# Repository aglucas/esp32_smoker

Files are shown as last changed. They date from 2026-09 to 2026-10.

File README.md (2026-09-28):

# esp32_smoker

ESP32 firmware project for a smoker controller, built on [ESP-IDF v5.5.3](https://github.com/espressif/esp-idf/releases/tag/v5.5.3). Targets the [Seeed Studio XIAO ESP32C3](https://wiki.seeedstudio.com/XIAO_ESP32C3_Getting_Started/).

## Features

- 3 NTC thermistor probes (probe 0 = pit, 1..2 = meat), read in °F. Beta model by default, or per-probe Steinhart-Hart coefficients once calibrated. Unplugged/shorted probes show as `--`.
- Phone-friendly web dashboard at `http://smoker.local` (mDNS) or the device IP: live temps, pit low/high alarm, pit target and per-probe meat targets, and a graph (pit target drawn as a green line, low/high as red lines) of the last 1/2/3/6 hours with touch/hover readout. Fully self-contained (no CDN), so it also works on the offline setup AP.
- Alerts: pit too low (only after it stays low for the "Low alarm delay", 60 s by default and set on the pit card, so opening the lid doesn't trigger it, and only armed once the pit first reaches temp), pit too high, pit probe lost, meat "almost done", meat done. Delivered by [ntfy.sh](https://ntfy.sh) push notifications (set up from the dashboard). Settings are saved in NVS.
- Wi-Fi: tries `DEFAULT_STA_SSID`, then credentials saved in NVS; if neither connects it falls back to a SoftAP (`ESP32-Smoker-XXXX`, password `smoker1234` by default) and the dashboard shows a network picker. Alerts need internet, so none are sent in AP mode (they queue until it reconnects). While in AP mode it retries your Wi-Fi every 60 s (`WIFI_RECONNECT_SEC`) in the background, keeping the AP up meanwhile, and switches back automatically once it connects.
- Graph history: one sample every 30 s for 12 h, kept in RAM. After a power cut, once the clock syncs over the internet (a few seconds after Wi-Fi connects), the graph reloads the last 12 h from the flash log at 1-minute resolution. The outage shows as a break in the lines. On the offline setup AP the clock never syncs, so the graph starts empty (the flash log still has everything).
- Flash log: one CSV row per minute (`uptime_s,unix_time,local_time,<probe>_f...`) saved to a LittleFS partition in the ESP32's internal flash, so no SD card is needed. Download it from the dashboard's **Data log** panel. **Start new recording** (next to it) deletes the log, clears the graph, and re-arms alerts and the meat target-hit checks; settings are kept. `unix_time` and `local_time` (Mountain Time, set by `LOG_TIMEZONE`) are blank until SNTP syncs. When the active file passes 1 MB it is rotated, and the oldest data is dropped, so the log keeps roughly the last 2-4 weeks of cooking.
- Cook steps: named, timed plans (for example "3-2-1 ribs") edited in the **Cook steps** panel. Each step has a name, minutes, an action and a target temp. Plans are saved on the LittleFS partition (`plans.json`); up to 10 plans with up to 12 steps each. **Start** sends step 1's alert right away, then each next step's alert when the previous step's time is up (for example "Step 2/4: The wrap (120 min) - wrapped in foil ribs. Target 120F"), and a final "all steps done" alert. The target temp is only shown in the alert. The running plan is saved too, so after a power cut it resumes once the clock syncs, and a step that began during the outage is sent late with a note.
- Fan control: a 12 V PC fan on GPIO6 (D4) through a 2N2222, driven by slow (50 Hz) PWM, which lets a 2/3-wire PC fan run steadily at lower speeds than fast PWM. **Auto** runs a PID that holds the pit target (starting with Kp = 4 %/°F, Ki = Kd = 0); **Manual** holds a fixed %; **Off**. In Auto the fan is off when no pit target is set or the pit probe has no reading. If the pit reaches the high alarm, the fan turns off and stays off until the pit has cooled back down to the target. The PID output (0-100 %) drives the fan directly; with slow PWM the fan runs steadily down to about 5 %, and any non-zero output below that is raised to 5 % (`FAN_MIN_PCT`). A 1 s full-speed kick runs when the fan starts from stopped. **Fan alert** (Auto mode): if the fan stays at or above a set % for a set time (90 % for 15 min by default, both set in the Fan panel, 0 = off), one alert is sent to say the fire may be low on fuel or the vents may be wrong; it re-arms once the fan drops below that %. The fan % is plotted on its own graph (0-100 %, half the height) under the temperature graph, sharing its time axis, and logged in the CSV (`fan_pct`).
- JSON API: `GET /api/now`, `GET /api/history`, `POST /api/settings` (form-encoded `alertsOn`, `pitLow`, `pitHigh`, `pitTarget`, `pitLowDelay`, `t1`, `t2`), `POST /api/test`, `GET /api/log.csv`, `POST /api/reset`, `POST /api/hit/clear` (`{"probe":1}`, clears a meat target-hit check), `POST /api/fan` (`{"mode":"auto","manual":50,"kp":4,"ki":0,"kd":0,"alertPct":90,"alertMin":15}`), `POST /api/ntfy` (`{"enabled":true,"server":"https://ntfy.sh","topic":"..."}`), `GET/POST /api/plans`, `POST /api/plan/start` (`{"name":"..."}`), `POST /api/plan/stop`, `GET /api/scan`, `POST /api/wifi` (`{"ssid":"...","password":"..."}`).

## Wiring

Each probe is a voltage divider: `3V3 → rRef → pin → thermistor → GND`. Probes must be on ADC1. The XIAO exposes only three ADC1 pins (A0-A2); A3 is on ADC2, which is unreliable on the C3 and blocked by ESP-IDF.

| Signal | XIAO pin | GPIO | Notes |
|---|---|---|---|
| Pit probe | A0 | GPIO2 | ADC1_CH2, rRef 100k (see strapping note) |
| Meat 1 | A1 | GPIO3 | ADC1_CH3, rRef 100k |
| Meat 2 | A2 | GPIO4 | ADC1_CH4, rRef 100k |
| Fan | D4 | GPIO6 | PWM to the 2N2222 base (see fan note) |

- **Probes and resistor values:** all three probes are Maverick ET-72/73 style (about 200 kΩ at room temperature) on 100k divider resistors, using HeaterMeter's Steinhart-Hart coefficients for that probe (`MAVERICK_SH` in [main/config.h](main/config.h)). They were verified against a 180 °F oven and boiling water (about 202 °F at 5,400 ft). The C3's ADC is only accurate up to about 2.5 V (the classic ESP32 reaches about 3.1 V), so below about 49 °F a probe can't be told apart from an unplugged one, and the dashboard shows "below 49° or unplugged".
- **Strapping pin:** GPIO2 (A0) is sampled at reset to choose the boot mode. The pit probe on A0 holds it at 3.3 V when unplugged and about 2.2 V at room temperature. If the board ever fails to boot with the pit probe plugged in, unplug it during power-up.
- **Fan:** GPIO6 → ~220 Ω → 2N2222 base; emitter to GND; collector to the fan's black (−) wire; fan red (+) to 12 V. The 12 V supply's ground must be connected to the XIAO's GND. Add a diode (1N4148 or 1N5819) across the fan, cathode to +12 V, to absorb switching spikes, and a 10 kΩ resistor from base to GND so the fan stays off while the board boots. Around 220 Ω gives the base roughly 10 mA, enough to fully switch a typical 0.1-0.3 A PC fan (1 kΩ may leave the transistor only part-on and hot).
- **Antenna:** the XIAO ESP32C3 needs its external antenna attached for usable Wi-Fi range.

Probe names, pins, resistor values and thermistor constants are in `PROBE_TABLE` in [main/config.h](main/config.h). For accuracy, measure the 3V3 rail and set `VSUPPLY_MV`, and set `OPEN_MV` about 50 mV below what an unplugged probe reads. The serial log prints mV and ohms for every probe every 2 s, which you can use for calibration.

## Alerts setup

- **ntfy:** install the ntfy app. On the dashboard, tap **Change** next to *Notifications* to turn ntfy on or off and set the server and topic. **Random** generates a hard-to-guess topic, and the panel shows a link to subscribe to it. The settings are saved in NVS; `NTFY_SERVER`, `NTFY_TOPIC` and `USE_NTFY` in [main/config.h](main/config.h) are only first-boot defaults.

Use **Send test alert** on the dashboard to check delivery.

- **Offline delivery:** alerts raised while Wi-Fi or the internet is down are queued and sent once it's back, marked "(sent N min late)". Failed sends are retried every 30 s. Alerts undelivered after 2 hours are dropped, and a power cut loses the queue.
- **Pit low after a reboot:** the pit low alarm stays armed after a reboot if the board was running within the last 2 hours (`PIT_ARM_RESTORE_MIN`), so a power blip mid-cook doesn't disarm it. A cold start the next day begins disarmed, as usual.

## Prerequisites

- ESP-IDF v5.5.3 installed and set up (`install.bat` / `export.bat` from the IDF repo, or the ESP-IDF VS Code extension).

## Build

```
idf.py set-target esp32c3
idf.py build
```

To have the smoker join your Wi-Fi without using the setup page, copy `main/secrets.h.example` to `main/secrets.h` and fill in your network name and password. `secrets.h` is git-ignored, so the password never gets committed. Without it, the firmware still builds and you pick a network from the dashboard instead.

## Flash & Monitor

```
idf.py -p <PORT> flash monitor
```

`flash` writes the bootloader, the partition table ([partitions.csv](partitions.csv)) and the app together. NVS, which holds Wi-Fi credentials and alert settings, keeps the same place in flash, so those survive a firmware update. The log partition is formatted automatically on first boot.

The XIAO's USB-C port is the C3's built-in USB serial port, and the log console is set to use it. If flashing can't connect, hold **BOOT**, tap **RESET**, then release **BOOT** to enter download mode.

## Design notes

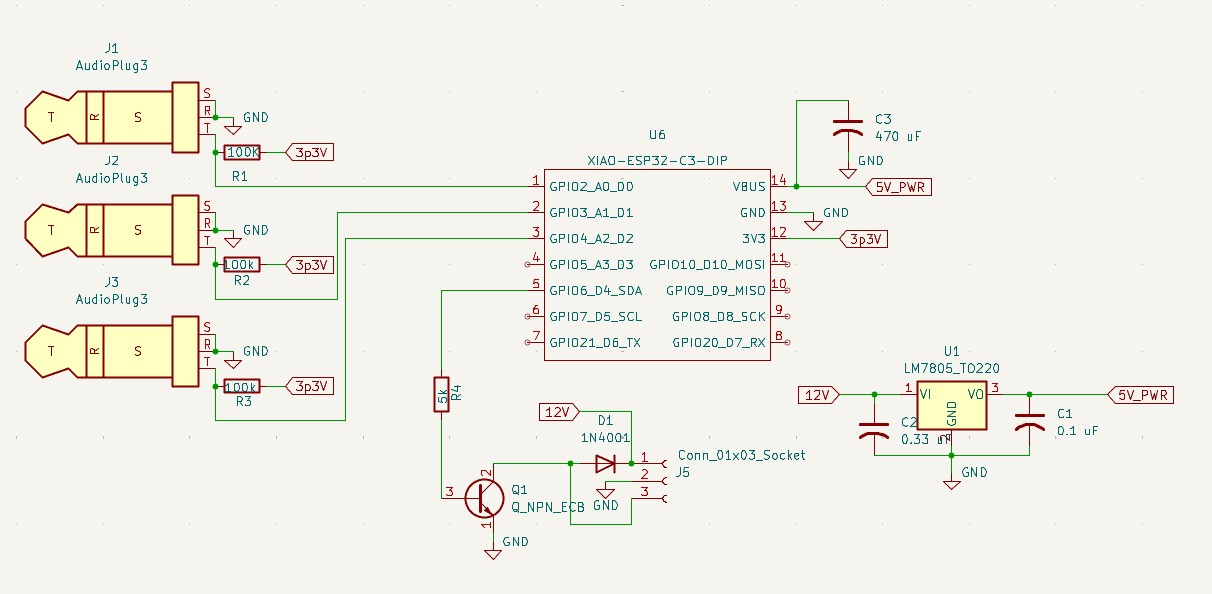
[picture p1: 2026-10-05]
smoker_circuit.jpg

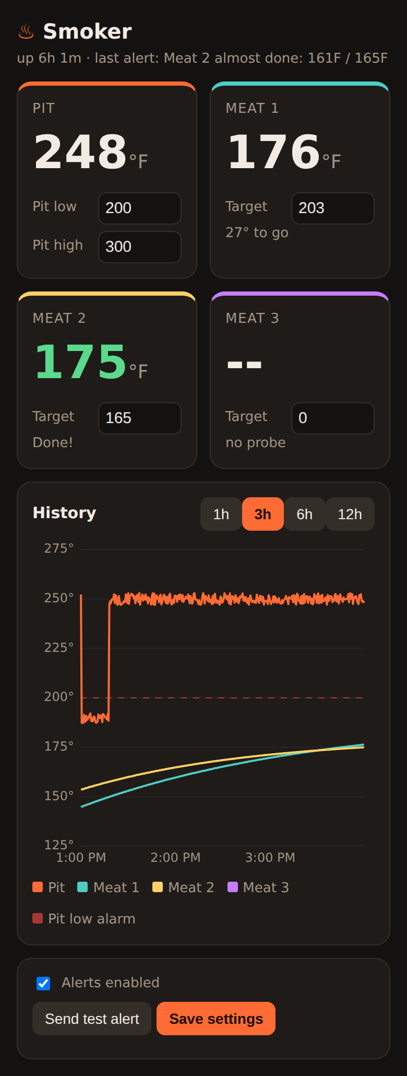
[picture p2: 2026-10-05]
sample_page.png

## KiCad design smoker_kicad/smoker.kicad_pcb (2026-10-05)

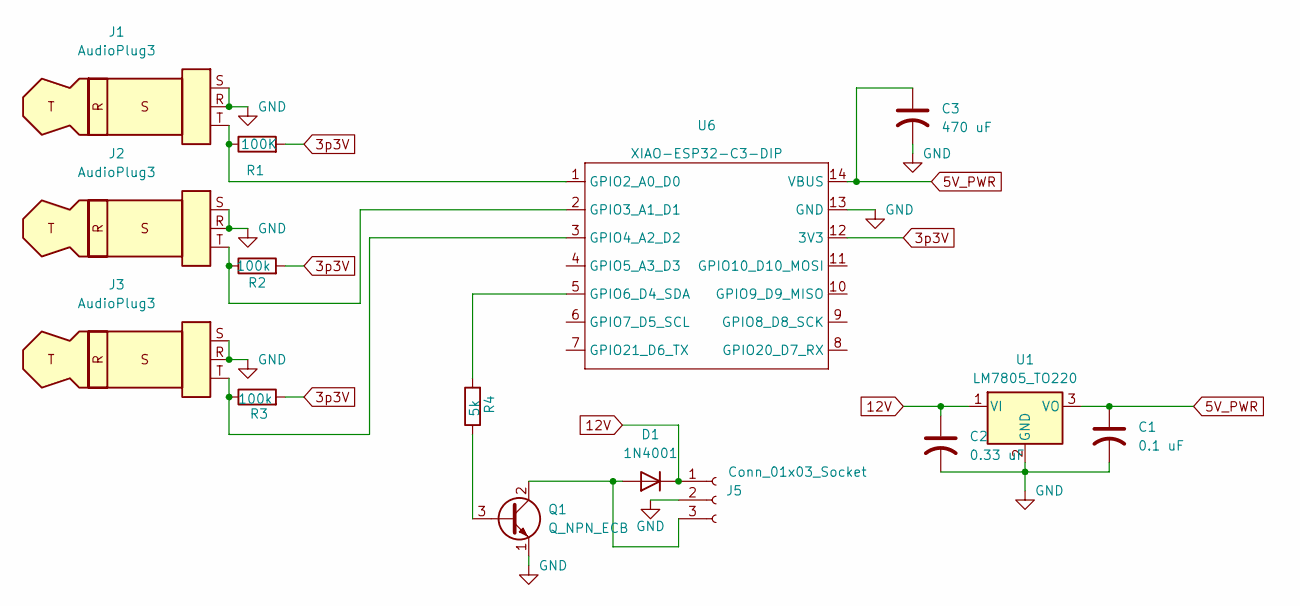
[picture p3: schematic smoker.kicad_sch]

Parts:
C1: 0.1 uF; C_0805_2012Metric
C2: 0.33 uF; C_0805_2012Metric
C3: 470 uF; C_Radial_D10.0mm_H16.0mm_P5.00mm
D1: 1N4001; D_DO-41_SOD81_P10.16mm_Horizontal
J1, J2, J3: AudioPlug3; PJ-208_XKB_2.5mm_ThroughHole2
J5: Conn_01x03_Socket; JST_XH_B3B-XH-A_1x03_P2.50mm_Vertical
Q1: Q_NPN_ECB; TO-92
R1: 100K; R_0805_2012Metric_Pad1.20x1.40mm_HandSolder
R2, R3: 100k; R_0805_2012Metric_Pad1.20x1.40mm_HandSolder
R4: 5k; R_0805_2012Metric_Pad1.20x1.40mm_HandSolder
U1: LM7805_TO220; TO-220-3_Vertical
U6: XIAO-ESP32-C3-DIP; MCU_Seeed_ESP32C3

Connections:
3p3V: R1.2, R2.2, R3.2, U6.12 (3V3)
5V_PWR: C1.1, C3.1, U1.3 (VO), U6.14 (VBUS)
12V: C2.1, D1.1 (K), J5.1, U1.1 (VI)
GND: C1.2, C2.2, C3.2, J1.R, J1.S, J2.R, J2.S, J3.R, J3.S, J5.2, Q1.1 (E), U1.2 (GND), U6.13 (GND)
unnamed: D1.2 (A), J5.3, Q1.2 (C)
unnamed: Q1.3 (B), R4.1
unnamed: J1.T, R1.1, U6.1 (GPIO2_A0_D0)
unnamed: J2.T, R2.1, U6.2 (GPIO3_A1_D1)
unnamed: J3.T, R3.1, U6.3 (GPIO4_A2_D2)
unnamed: R4.2, U6.5 (GPIO6_D4_SDA)

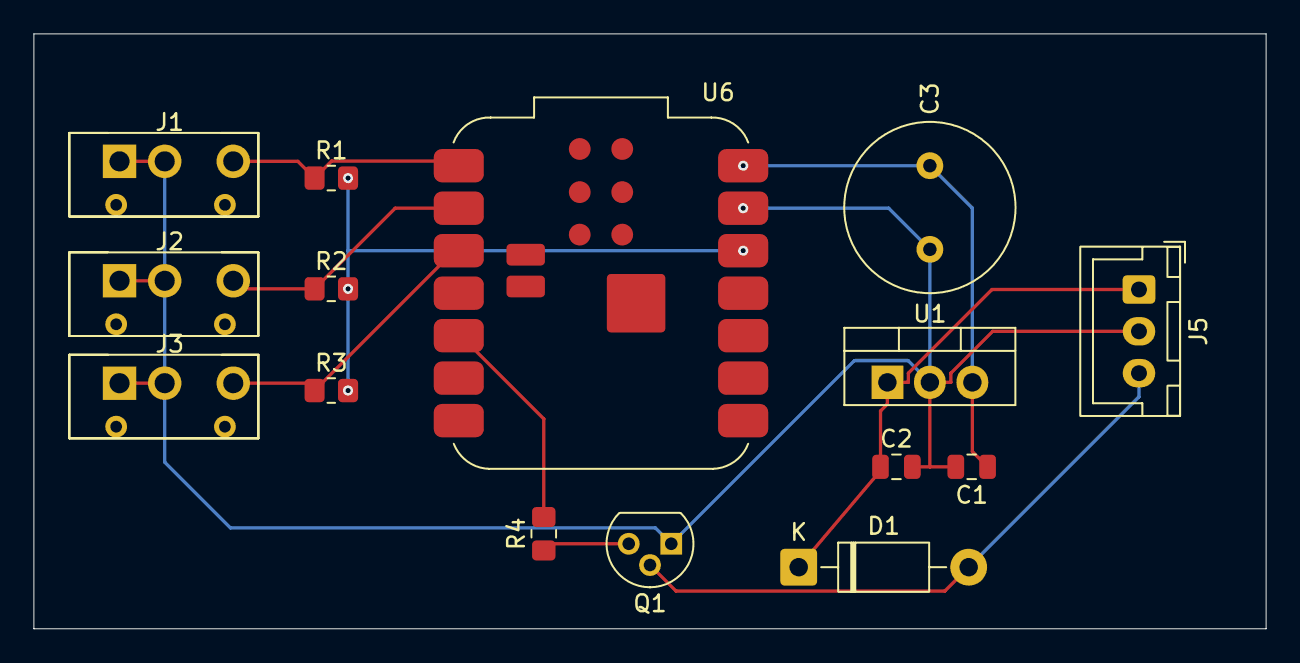
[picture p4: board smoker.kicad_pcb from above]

Board: 2 copper layers, 73.7 x 35.6 mm, 15 parts (0 on the bottom side), 10 nets.

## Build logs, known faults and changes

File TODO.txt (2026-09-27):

TODO: Over-the-air (OTA) firmware updates
==========================================

Goal: upload a new build (build/esp32_smoker.bin) from the web page instead
of flashing over USB, with automatic rollback if the new firmware is bad.

1. Partition table (partitions.csv) - two app slots, smaller log area
---------------------------------------------------------------------
Keep nvs and phy_init exactly where they are so Wi-Fi credentials and all
saved settings survive the switch. App partitions must be 64 KB (0x10000)
aligned.

  # Name,   Type, SubType,  Offset,   Size
  nvs,      data, nvs,      0x9000,   0x6000      (unchanged)
  phy_init, data, phy,      0xf000,   0x1000      (unchanged)
  ota_0,    app,  ota_0,    0x10000,  0x1B0000    (~1.69 MB)
  ota_1,    app,  ota_1,    0x1C0000, 0x1B0000    (~1.69 MB)
  otadata,  data, ota,      0x370000, 0x2000
  storage,  data, littlefs, 0x372000, 0x8E000     (~568 KB)

- App today is ~1.2 MB, so each slot has ~0.5 MB headroom.
- Remove the "factory" partition.
- Double-check the layout with:
    python %IDF_PATH%\components\partition_table\gen_esp32part.py build\partition_table\partition-table.bin

2. Log size: keep ~24 h instead of weeks
----------------------------------------
- A row (incl. fan_pct) is ~60 bytes, 1/min => ~86 KB per 24 h.
- config.h: LOG_ROTATE_BYTES (1024 * 1024) -> (96 * 1024).
  Two files => always >= 24 h kept, <= ~200 KB used.
- Update the README (log keeps the last 24-48 h, not 2-4 weeks) and the
  comment in config.h.
- Graph restore only reads the last 12 h, so it is unaffected.
- Flash wear at this size: worst case (24/7 logging) ~25 years; for normal
  cooking use, effectively unlimited.

3. GOTCHA: LittleFS "never auto-format" flag
--------------------------------------------
data_log.c only formats the storage partition if the NVS flag
"smoker"/"log_fmt" is 0. NVS survives the partition change, so the flag will
still be 1 while the storage partition has MOVED and is blank => mount fails
and logging stays disabled.

Fix: record which partition was formatted, e.g. save the storage
partition's offset (esp_partition_t.address) instead of a 0/1 flag, and
allow a format when the saved offset differs from the current one.

4. Bootloader / sdkconfig
-------------------------
- sdkconfig.defaults: CONFIG_BOOTLOADER_APP_ROLLBACK_ENABLE=y
  (keep CONFIG_PARTITION_TABLE_CUSTOM=y / partitions.csv).
- The bootloader changes, so the switch needs one USB flash of everything
  (idf.py -p PORT flash writes bootloader, partition table, otadata, app).
- Optional: set a firmware version (PROJECT_VER in CMakeLists.txt or from
  "git describe") so the page can show what is running.

5. Firmware: upload endpoint (new module, e.g. main/ota_update.c)
------------------------------------------------------------------
- POST /api/ota (raw .bin in the request body):
    esp_ota_get_next_update_partition(NULL)
    esp_ota_begin(part, OTA_WITH_SEQUENTIAL_WRITES, &handle)
    loop httpd_req_recv() in ~4 KB chunks -> esp_ota_write()
    esp_ota_end()  (validates the image)
    esp_ota_set_boot_partition(part)
    reply {"ok":true}, then esp_restart() after ~1 s (esp_timer)
  On any error: esp_ota_abort(), reply {"ok":false,"why":...}.
- Raise httpd config.recv_wait_timeout (upload takes a while over Wi-Fi) and
  check the httpd task stack is big enough; bump max_uri_handlers if needed.
- Auth: require a password (e.g. OTA_PASSWORD in main/secrets.h, sent as a
  header) so nobody else on the LAN can load firmware.
- GET /api/now: add the running firmware version
  (esp_app_get_description()->version) and which slot is running.

6. Firmware: rollback safety
----------------------------
- After an update the new app boots in "pending verify" state.
- Call esp_ota_mark_app_valid_cancel_rollback() once the app is healthy,
  e.g. Wi-Fi started + web server running + ~60 s without a crash.
- If it crashes or reboots before that, the bootloader switches back to the
  previous slot automatically.
- Log which slot booted and whether a rollback happened; maybe send an
  alert "Firmware rolled back to <version>".

7. Web page (index.html)
------------------------
- New "Firmware update" panel (near Data log): current version, file
  picker for the .bin, password field, Upload button.
- Use XMLHttpRequest (not fetch) to show upload progress %.
- Warn before uploading if a cook plan is running or the fan is on: the
  reboot takes ~5-10 s, during which the fan is off and nothing is measured.
  (Afterwards the graph, plan timer and pit-low arm all restore.)
- After "ok": show "Rebooting...", then poll /api/now until it answers and
  show the new version.

8. Migration steps (one time)
-----------------------------
1. Download the CSV log (it will be lost - the storage partition moves).
2. Note/screenshot the cook plans (also lost). Consider adding a plans
   export/import (download/upload plans.json) first.
3. Build, then USB flash everything: idf.py -p PORT flash monitor
4. Check: settings and Wi-Fi kept, log partition formatted, logging works.
5. Test an OTA upload, then test rollback (e.g. upload a build that
   deliberately never marks itself valid, and confirm it reverts).

Alternatives considered
-----------------------
- ESP32 pulls updates from a URL (esp_https_ota, e.g. GitHub releases) with
  an "Update now" button. More infrastructure; page upload is simpler for a
  single smoker.

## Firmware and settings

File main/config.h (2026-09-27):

#pragma once

// =====================================================================
//                            USER CONFIG
// =====================================================================

// ---- Wi-Fi ----
#define WIFI_CONNECT_TIMEOUT_MS   15000
#define WIFI_MAX_RETRY            5
// While running its own fallback network, try your Wi-Fi again this often
// (one attempt each time, alternating secrets.h and the saved network).
#define WIFI_RECONNECT_SEC        60

// Default network to try before saved credentials / fallback AP. Set it in
// main/secrets.h (copy secrets.h.example); that file is git-ignored so the
// password stays out of the repo. Without it, the default network is skipped.
#if __has_include("secrets.h")
#include "secrets.h"
#endif
#ifndef DEFAULT_STA_SSID
#define DEFAULT_STA_SSID          ""
#define DEFAULT_STA_PASSWORD      ""
#endif

#define AP_SSID_PREFIX            "ESP32-Smoker-"
#define AP_PASSWORD               "smoker1234"   // WPA2-PSK, >=8 chars. Change me.
#define AP_CHANNEL                1
#define AP_MAX_CONN               4

#define MDNS_HOSTNAME             "smoker"       // -> http://smoker.local

// ---- Alert delivery (ntfy push notifications) ----
// Alerts need internet, so nothing is sent while only the setup AP is up.
#define USE_NTFY                  1        // default only; on/off is set on the web page

// ntfy: install the ntfy app on your phone, subscribe to the topic.
// Anyone who knows the topic name can read it, so make it unguessable.
// These are first-boot defaults: the server, topic and on/off switch can be
// changed on the web page ("Change" next to Notifications) and are saved in NVS.
#define NTFY_SERVER               "https://ntfy.sh"
#define NTFY_TOPIC                "smoker-change-me-7q2x9k"

// ---- Temperature probes (Seeed XIAO ESP32C3) ----
// Only ADC1 is usable: on the C3, ADC2 is unreliable and blocked by ESP-IDF.
// The XIAO breaks out three ADC1 pins: A0 (GPIO2), A1 (GPIO3), A2 (GPIO4).
// On the C3, ADC1 channel N is GPION.
//
// Divider per channel: 3V3 --[rRef]-- ADC pin --[thermistor]-- GND
//
// Measure the 3V3 pin with a multimeter and enter it here (in mV).
#define VSUPPLY_MV                3300.0f
// Readings at/above this are treated as "no probe plugged in". The C3 ADC is
// only accurate up to ~2.5 V and saturates a little above that, so unplug a
// probe, watch the serial log to see what your board reads, then set this
// ~50 mV below that value.
#define OPEN_MV                   2600.0f
#define SHORT_MV                  20.0f
#define ADC_SAMPLE_COUNT          64       // oversampling per reading

// Probe 0 is always the pit; the rest are meat probes.
// Beta model is used while shC == 0; set shA/shB/shC to use Steinhart-Hart.
//
// All three probes are Maverick ET-72/73 style (~200k at room temp) on 100k
// divider resistors, using HeaterMeter's Steinhart-Hart coefficients for that
// probe. On the meat probes these matched room temp, a 180 F oven and boiling
// water (~202 F at 5,400 ft) within ~1.5 F.
//   Pit:  225 F ~440 mV (~5.5 mV/F), 350 F ~110 mV (~0.8 mV/F).
//   Meat: 165 F ~1.0 V, 203 F ~600 mV.
// Below ~49 F the voltage passes OPEN_MV (the C3's ~2.5 V ceiling), so a
// colder probe can't be told apart from an unplugged one; the web page and
// log show "below 49 or unplugged".
//
// GPIO2 (A0) is a boot strapping pin. An unplugged pit probe holds it at
// 3.3 V; a room-temp probe at ~2.2 V and a hot one much lower. If the board
// ever fails to boot with the pit probe plugged in, unplug it at power-up.
#define MAVERICK_SH               2.4723753e-4, 2.3402251e-4, 1.3879768e-7
#define NUM_PROBES                3
#define PROBE_TABLE { \
    /* name      adc channel    rRef       r0         t0C    beta     shA, shB, shC */ \
    { "Pit",     ADC_CHANNEL_2, 100000.0f, 200000.0f, 25.0f, 3950.0f, MAVERICK_SH }, /* A0 / GPIO2 */ \
    { "Meat 1",  ADC_CHANNEL_3, 100000.0f, 200000.0f, 25.0f, 3950.0f, MAVERICK_SH }, /* A1 / GPIO3 */ \
    { "Meat 2",  ADC_CHANNEL_4, 100000.0f, 200000.0f, 25.0f, 3950.0f, MAVERICK_SH }, /* A2 / GPIO4 */ \
}

// ---- Alert defaults (changeable from the web page, saved in NVS) ----
#define DEFAULT_PIT_LOW_F         200.0f   // 0 = off
#define DEFAULT_PIT_HIGH_F        300.0f   // 0 = off
// Index 0 is the pit target (drawn on the graph only, no alert); 0 = off.
#define DEFAULT_TARGETS_F         { 225, 203, 165 }

#define DEFAULT_PIT_LOW_DELAY_S   60       // pit must stay low this long before alerting (set on the web page)
#define PIT_LOW_DELAY_MAX_S       3600
#define PIT_HYST_F                10.0f    // pit high re-arms once this far below the limit
// After a reboot, pit low stays armed only if the board was last running
// (armed) within this long - a power blip mid-cook, not tomorrow's cold start.
#define PIT_ARM_RESTORE_MIN       120
#define ALERT_RETRY_SEC           30       // retry a failed ntfy send this often
#define ALERT_MAX_AGE_MIN         120      // give up on alerts undelivered this long
#define NEAR_DONE_F               5.0f     // "almost done" heads-up (0 = off)
#define MEAT_REARM_F              15.0f    // re-arm meat alert if temp drops this far

// ---- Fan (12 V PC fan, low-side 2N2222 switch) ----
// GPIO high = transistor on = fan on. Driven by LEDC PWM.
#define FAN_GPIO                  6        // D4 / GPIO6
// Slow PWM: each pulse fully powers the fan's own driver chip and the rotor
// smooths it out, so a 2/3-wire PC fan runs steadily at much lower speeds
// than with fast (25 kHz) PWM, which starves its electronics. May hum a
// little. Range with the 13-bit resolution in fan_control.c: ~10 Hz-9 kHz.
#define FAN_PWM_FREQ_HZ           50
#define FAN_KICK_MS               1000     // run 100% this long when starting from stopped
#define FAN_MIN_PCT               5.0f     // any non-zero output below this is raised to it (fan stalls lower)
// PID defaults (all editable on the web page and saved in NVS). The PID holds
// the pit target from the pit card. Units:
//   Kp: % fan per F below target
//   Ki: % fan per (F below target x minute), accumulated
//   Kd: % fan per (F/minute the pit is rising), subtracted
#define DEFAULT_FAN_KP            4.0f
#define DEFAULT_FAN_KI            0.0f
#define DEFAULT_FAN_KD            0.0f
// Fan alert (Auto mode): fan at or above this % for this long usually means
// the fire is low on fuel or the vents are wrong. Either one 0 = off.
#define DEFAULT_FAN_ALERT_PCT     90.0f
#define DEFAULT_FAN_ALERT_MIN     15.0f

// ---- Timing / history ----
#define READ_MS                   2000     // read probes & check alerts
#define SAMPLE_SEC                30       // web graph resolution
#define HISTORY_HOURS             12       // web graph memory (RAM)
#define LOG_INTERVAL_MS           60000    // flash CSV log cadence

// Not a setting: time(NULL) above this means SNTP has set the clock. Before
// that (and always on the offline setup AP) only time-since-boot is known.
#define UNIX_TIME_VALID           1700000000

// ---- Temperature log (LittleFS "storage" partition in internal flash) ----
// Rows go to log.csv; when it passes LOG_ROTATE_BYTES it becomes log_old.csv
// (replacing the previous one) and a new log.csv starts, so the log never
// uses more than ~2x this. ~40 bytes/row at 1 row/min is ~60 KB per day, so
// 1 MB per file keeps roughly the last 2-4 weeks of cooking.
#define LOG_ROTATE_BYTES          (1024 * 1024)
// POSIX TZ string for the local_time column (America/Denver).
#define LOG_TIMEZONE              "MST7MDT,M3.2.0,M11.1.0"

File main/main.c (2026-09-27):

#include <math.h>
#include <stdio.h>
#include <stdlib.h>
#include <time.h>

#include "esp_err.h"
#include "esp_log.h"
#include "esp_timer.h"
#include "esp_event.h"
#include "esp_netif.h"
#include "nvs_flash.h"
#include "mdns.h"
#include "freertos/FreeRTOS.h"
#include "freertos/task.h"

#include "config.h"
#include "wifi_manager.h"
#include "temp_sensor.h"
#include "data_log.h"
#include "web_server.h"
#include "alerts.h"
#include "cook_plan.h"
#include "fan_control.h"

static const char *TAG = "esp32_smoker";

static void start_mdns(void)
{
    if (mdns_init() != ESP_OK) {
        ESP_LOGW(TAG, "mDNS init failed; use the IP address instead");
        return;
    }
    mdns_hostname_set(MDNS_HOSTNAME);
    mdns_instance_name_set("ESP32 Smoker");
    mdns_service_add(NULL, "_http", "_tcp", 80, NULL, 0);
    ESP_LOGI(TAG, "Open http://%s.local", MDNS_HOSTNAME);
}

// Serial output doubles as a calibration log (mV + resistance per probe).
static void log_readings(const probe_reading_t r[NUM_PROBES], float fan_pct)
{
    char line[256];
    int len = 0;
    for (int i = 0; i < NUM_PROBES && len < (int)sizeof(line); i++) {
        char temp[12];
        if (r[i].ohms == -1) {
            snprintf(temp, sizeof(temp), "<%.0f/open", temp_sensor_min_readable_f(i));
        } else if (r[i].ohms == -2) {
            snprintf(temp, sizeof(temp), "short");
        } else if (isnan(r[i].temp_f)) {
            snprintf(temp, sizeof(temp), "--");
        } else {
            snprintf(temp, sizeof(temp), "%.1f", r[i].temp_f);
        }
        len += snprintf(line + len, sizeof(line) - len, "%s%s: %s F (%.0f mV, %.0f ohm)",
                        i ? " | " : "", temp_sensor_probe_name(i), temp, r[i].mv, r[i].ohms);
    }
    if (len < (int)sizeof(line)) {
        snprintf(line + len, sizeof(line) - len, " | Fan: %.0f%%", fan_pct);
    }
    ESP_LOGI(TAG, "%s", line);
}

// After a power cut the graph (RAM) starts empty. Once SNTP sets the clock we
// know how long the power was out, so reload the graph window from the flash
// log. Without internet (setup AP) the clock never syncs and this never runs.
static void restore_graph_from_log(int64_t now_us)
{
    uint32_t unix_now = (uint32_t)time(NULL);
    hist_entry_t *rows = NULL;
    size_t n = 0;
    if (data_log_read_recent(unix_now - HISTORY_HOURS * 3600, &rows, &n) != ESP_OK) {
        n = 0;
    }
    temp_sensor_history_time_synced(unix_now, (uint32_t)(now_us / 1000000), rows, n);
    free(rows);
}

void app_main(void)
{
    esp_err_t ret = nvs_flash_init();
    if (ret == ESP_ERR_NVS_NO_FREE_PAGES || ret == ESP_ERR_NVS_NEW_VERSION_FOUND) {
        ESP_ERROR_CHECK(nvs_flash_erase());
        ret = nvs_flash_init();
    }
    ESP_ERROR_CHECK(ret);

    ESP_ERROR_CHECK(esp_netif_init());
    ESP_ERROR_CHECK(esp_event_loop_create_default());

    ESP_ERROR_CHECK(fan_control_init());   // first, so the fan output starts off
    ESP_ERROR_CHECK(temp_sensor_init());
    if (data_log_init() != ESP_OK) {
        ESP_LOGW(TAG, "Continuing without flash logging");
    }
    ESP_ERROR_CHECK(alerts_init());
    ESP_ERROR_CHECK(cook_plan_init());
    ESP_ERROR_CHECK(wifi_manager_start());
    start_mdns();
    ESP_ERROR_CHECK(web_server_start());

    ESP_LOGI(TAG, "esp32_smoker up: reading every %ds, graph every %ds, flash log every %ds",
             READ_MS / 1000, SAMPLE_SEC, LOG_INTERVAL_MS / 1000);

    temp_sensor_update_current();
    temp_sensor_push_history();
    int64_t last_hist_us = esp_timer_get_time();
    int64_t last_log_us = 0;
    bool clock_synced = false;
    TickType_t last_wake = xTaskGetTickCount();

    while (1) {
        temp_sensor_update_current();

        probe_reading_t r[NUM_PROBES];
        float temps_f[NUM_PROBES];
        temp_sensor_get_current(r);
        for (int i = 0; i < NUM_PROBES; i++) {
            temps_f[i] = r[i].temp_f;
        }
        alerts_check(temps_f);
        cook_plan_tick();

        alert_settings_t settings;
        alerts_get_settings(&settings);
        fan_control_update(temps_f[0], settings.target[0], settings.pit_high);
        fan_status_t fan;
        fan_control_get_status(&fan);
        temp_sensor_set_fan_pct(fan.pct);
        log_readings(r, fan.pct);

        int64_t now_us = esp_timer_get_time();
        if (!clock_synced && time(NULL) > UNIX_TIME_VALID) {
            clock_synced = true;
            restore_graph_from_log(now_us);
        }
        if (now_us - last_hist_us >= (int64_t)SAMPLE_SEC * 1000000) {
            last_hist_us = now_us;
            temp_sensor_push_history();
        }
        if (last_log_us == 0 || now_us - last_log_us >= (int64_t)LOG_INTERVAL_MS * 1000) {
            last_log_us = now_us;
            data_log_append((uint32_t)(now_us / 1000000), temps_f, fan.pct);
        }

        vTaskDelayUntil(&last_wake, pdMS_TO_TICKS(READ_MS));
    }
}

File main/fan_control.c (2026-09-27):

#include <math.h>
#include <stddef.h>
#include <string.h>

#include "fan_control.h"
#include "config.h"
#include "alerts.h"

#include "driver/ledc.h"
#include "esp_log.h"
#include "esp_timer.h"
#include "nvs.h"
#include "freertos/FreeRTOS.h"
#include "freertos/semphr.h"

static const char *TAG = "fan";

#define NVS_NAMESPACE   "smoker"
#define NVS_KEY_FAN     "fan2"   // current layout
#define NVS_KEY_FAN_V1  "fan"    // older layouts: only mode..kd are read from it
#define LEDC_MODE       LEDC_LOW_SPEED_MODE
#define LEDC_TIMER      LEDC_TIMER_0
#define LEDC_CHANNEL    LEDC_CHANNEL_0
// 80 MHz / (freq x 2^bits) must be a clock divider of 1..1023: 13 bits covers
// ~10 Hz to ~9.7 kHz. (10 bits could not go below ~80 Hz.)
#define DUTY_BITS       LEDC_TIMER_13_BIT
#define DUTY_MAX        ((1u << 13) - 1)
#define D_FILTER        0.3f                   // smoothing for the derivative's noisy slope

static fan_settings_t s_cfg = {
    .mode = FAN_MODE_AUTO,
    .manual_pct = 50,
    .kp = DEFAULT_FAN_KP,
    .ki = DEFAULT_FAN_KI,
    .kd = DEFAULT_FAN_KD,
    .alert_pct = DEFAULT_FAN_ALERT_PCT,
    .alert_min = DEFAULT_FAN_ALERT_MIN,
};
static fan_status_t s_status = { .note = "", .high_for_s = -1 };

// Set when the pit reaches the high alarm; the fan then stays off until the
// pit has cooled back to the target (not just below the high alarm).
static bool s_over_high;

// Fan alert state
static int64_t s_high_since_us;   // 0 = fan not at/above alert_pct
static bool s_high_alert_sent;

// PID memory
static float s_integral;          // % contribution, kept within 0-100
static float s_prev_pit = NAN;
static float s_slope_f_per_min;   // filtered pit slope
static int64_t s_prev_us;

static float s_applied_pct;       // after the minimum-speed rule
static esp_timer_handle_t s_kick_timer;
static SemaphoreHandle_t s_mutex;

static void set_duty(float pct)
{
    uint32_t duty = (uint32_t)lroundf(pct / 100.0f * DUTY_MAX);
    ledc_set_duty(LEDC_MODE, LEDC_CHANNEL, duty);
    ledc_update_duty(LEDC_MODE, LEDC_CHANNEL);
}

// End of the start-up kick: drop from 100% to the real output.
static void kick_done(void *arg)
{
    set_duty(s_applied_pct);
}

// Caller holds s_mutex.
static void apply_locked(float pct)
{
    if (pct > 0 && pct < FAN_MIN_PCT) {
        pct = FAN_MIN_PCT;   // the fan stalls below this even after the kick
    }
    bool starting = pct > 0 && s_applied_pct == 0;
    s_applied_pct = pct;
    s_status.pct = pct;
    if (starting && FAN_KICK_MS > 0) {
        set_duty(100);
        esp_timer_stop(s_kick_timer);
        esp_timer_start_once(s_kick_timer, (uint64_t)FAN_KICK_MS * 1000);
    } else if (!esp_timer_is_active(s_kick_timer)) {
        set_duty(pct);
    } else if (pct == 0) {
        esp_timer_stop(s_kick_timer);
        set_duty(0);
    }
}

// Caller holds s_mutex.
static void reset_pid_locked(void)
{
    s_integral = 0;
    s_prev_pit = NAN;
    s_slope_f_per_min = 0;
    s_prev_us = 0;
}

static void load_settings(void)
{
    nvs_handle_t h;
    if (nvs_open(NVS_NAMESPACE, NVS_READONLY, &h) != ESP_OK) {
        return;
    }
    // Roomier buffer, pre-filled with defaults: a shorter blob leaves the
    // newer fields at their defaults, a longer one's extras are ignored.
    struct {
        fan_settings_t s;
        uint8_t spare[32];
    } tmp = { .s = s_cfg };
    size_t len = sizeof(tmp);
    const size_t base = offsetof(fan_settings_t, alert_pct);   // mode..kd
    if (nvs_get_blob(h, NVS_KEY_FAN, &tmp, &len) == ESP_OK && len >= base) {
        s_cfg = tmp.s;
    } else {
        // Older firmware stored other fields after kd (a since-removed Min %),
        // so take only mode..kd from it.
        tmp.s = s_cfg;
        len = sizeof(tmp);
        if (nvs_get_blob(h, NVS_KEY_FAN_V1, &tmp, &len) == ESP_OK && len >= base) {
            memcpy(&s_cfg, &tmp.s, base);
        }
    }
    ESP_LOGI(TAG, "Fan settings: mode %d, Kp %.2f Ki %.2f Kd %.2f, alert %.0f%% for %.0f min",
             s_cfg.mode, s_cfg.kp, s_cfg.ki, s_cfg.kd, s_cfg.alert_pct, s_cfg.alert_min);
    nvs_close(h);
}

esp_err_t fan_control_init(void)
{
    s_mutex = xSemaphoreCreateMutex();
    if (!s_mutex) {
        return ESP_ERR_NO_MEM;
    }
    ledc_timer_config_t timer = {
        .speed_mode = LEDC_MODE,
        .timer_num = LEDC_TIMER,
        .duty_resolution = DUTY_BITS,
        .freq_hz = FAN_PWM_FREQ_HZ,
        .clk_cfg = LEDC_AUTO_CLK,
    };
    ESP_ERROR_CHECK(ledc_timer_config(&timer));
    ledc_channel_config_t ch = {
        .gpio_num = FAN_GPIO,
        .speed_mode = LEDC_MODE,
        .channel = LEDC_CHANNEL,
        .timer_sel = LEDC_TIMER,
        .duty = 0,
        .hpoint = 0,
    };
    ESP_ERROR_CHECK(ledc_channel_config(&ch));

    const esp_timer_create_args_t kick_args = { .callback = kick_done, .name = "fan_kick" };
    ESP_ERROR_CHECK(esp_timer_create(&kick_args, &s_kick_timer));

    load_settings();
    ESP_LOGI(TAG, "Fan PWM on GPIO%d at %d Hz", FAN_GPIO, FAN_PWM_FREQ_HZ);
    return ESP_OK;
}
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

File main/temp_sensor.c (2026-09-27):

#include <math.h>
#include <stdlib.h>
#include <string.h>
#include <time.h>

#include "temp_sensor.h"
#include "config.h"

#include "esp_adc/adc_oneshot.h"
#include "esp_adc/adc_cali.h"
#include "esp_adc/adc_cali_scheme.h"
#include "esp_log.h"
#include "esp_timer.h"
#include "freertos/FreeRTOS.h"
#include "freertos/semphr.h"

static const char *TAG = "temp_sensor";

static const probe_config_t s_probes[NUM_PROBES] = PROBE_TABLE;

static adc_oneshot_unit_handle_t s_adc_handle;
static adc_cali_handle_t s_cali[NUM_PROBES];
static bool s_cali_ok[NUM_PROBES];

static probe_reading_t s_current[NUM_PROBES];
static SemaphoreHandle_t s_current_mutex;

static hist_entry_t s_history[HISTORY_LEN];
static uint32_t s_history_count = 0;
static uint32_t s_history_head = 0; // index to write next
static SemaphoreHandle_t s_history_mutex;

static bool adc_calibration_init(adc_unit_t unit, adc_channel_t channel, adc_atten_t atten, adc_cali_handle_t *out_handle)
{
    adc_cali_handle_t handle = NULL;
    esp_err_t ret = ESP_FAIL;
    bool calibrated = false;

#if ADC_CALI_SCHEME_CURVE_FITTING_SUPPORTED
    if (!calibrated) {
        adc_cali_curve_fitting_config_t cali_config = {
            .unit_id = unit,
            .chan = channel,
            .atten = atten,
            .bitwidth = ADC_BITWIDTH_DEFAULT,
        };
        ret = adc_cali_create_scheme_curve_fitting(&cali_config, &handle);
        if (ret == ESP_OK) {
            calibrated = true;
        }
    }
#endif
#if ADC_CALI_SCHEME_LINE_FITTING_SUPPORTED
    if (!calibrated) {
        adc_cali_line_fitting_config_t cali_config = {
            .unit_id = unit,
            .atten = atten,
            .bitwidth = ADC_BITWIDTH_DEFAULT,
        };
        ret = adc_cali_create_scheme_line_fitting(&cali_config, &handle);
        if (ret == ESP_OK) {
            calibrated = true;
        }
    }
#endif

    *out_handle = handle;
    if (calibrated) {
        ESP_LOGI(TAG, "ADC calibration ok (unit %d chan %d)", unit, channel);
    } else {
        ESP_LOGW(TAG, "ADC calibration not supported, using raw voltage estimate (unit %d chan %d)", unit, channel);
    }
    return calibrated;
}

static float read_mv(int probe)
{
    int64_t sum_mv = 0;
    int valid = 0;
    for (int i = 0; i < ADC_SAMPLE_COUNT; i++) {
        int raw = 0;
        if (adc_oneshot_read(s_adc_handle, s_probes[probe].channel, &raw) != ESP_OK) {
            continue;
        }
        int mv = 0;
        if (s_cali_ok[probe]) {
            if (adc_cali_raw_to_voltage(s_cali[probe], raw, &mv) != ESP_OK) {
                continue;
            }
        } else {
            mv = (int)(raw * VSUPPLY_MV / 4095.0f);
        }
        sum_mv += mv;
        valid++;
    }
    return valid ? (float)sum_mv / valid : NAN;
}

// Divider: 3V3 -- rRef -- node(ADC) -- probe -- GND
static float mv_to_ohms(const probe_config_t *p, float mv)
{
    if (isnan(mv) || mv >= OPEN_MV) return -1;  // open / unplugged
    if (mv <= SHORT_MV) return -2;               // shorted
    return p->r_ref * mv / (VSUPPLY_MV - mv);
}

static float ohms_to_f(const probe_config_t *p, float r)
{
    double inv_t;
    if (p->sh_c != 0) {
        double ln_r = log(r);
        inv_t = p->sh_a + p->sh_b * ln_r + p->sh_c * ln_r * ln_r * ln_r;
    } else {
        inv_t = 1.0 / (p->t0_c + 273.15) + log(r / p->r0) / p->beta;
    }
    double c = 1.0 / inv_t - 273.15;
    return c * 9.0 / 5.0 + 32.0;
}

esp_err_t temp_sensor_init(void)
{
    s_current_mutex = xSemaphoreCreateMutex();
    s_history_mutex = xSemaphoreCreateMutex();

    adc_oneshot_unit_init_cfg_t init_cfg = {
        .unit_id = ADC_UNIT_1,
    };
    ESP_ERROR_CHECK(adc_oneshot_new_unit(&init_cfg, &s_adc_handle));

    adc_oneshot_chan_cfg_t chan_cfg = {
        .bitwidth = ADC_BITWIDTH_DEFAULT,
        .atten = ADC_ATTEN_DB_12,   // ~0-3.1 V input range
    };
    for (int i = 0; i < NUM_PROBES; i++) {
        ESP_ERROR_CHECK(adc_oneshot_config_channel(s_adc_handle, s_probes[i].channel, &chan_cfg));
        s_cali_ok[i] = adc_calibration_init(ADC_UNIT_1, s_probes[i].channel, ADC_ATTEN_DB_12, &s_cali[i]);
        s_current[i] = (probe_reading_t){ .temp_f = NAN, .ohms = -1, .mv = 0 };
    }
    return ESP_OK;
}

const char *temp_sensor_probe_name(int probe)
{
    return s_probes[probe].name;
}

float temp_sensor_min_readable_f(int probe)
{
    const probe_config_t *p = &s_probes[probe];
    return ohms_to_f(p, p->r_ref * OPEN_MV / (VSUPPLY_MV - OPEN_MV));
}

void temp_sensor_update_current(void)
{
    probe_reading_t r[NUM_PROBES];
    for (int i = 0; i < NUM_PROBES; i++) {
        r[i].mv = read_mv(i);
        r[i].ohms = mv_to_ohms(&s_probes[i], r[i].mv);
        r[i].temp_f = NAN;
        if (r[i].ohms > 0) {
            float f = ohms_to_f(&s_probes[i], r[i].ohms);
            if (f >= -40 && f <= 750) {
                r[i].temp_f = f;
            }
        }
    }

    xSemaphoreTake(s_current_mutex, portMAX_DELAY);
    memcpy(s_current, r, sizeof(s_current));
    xSemaphoreGive(s_current_mutex);
}

void temp_sensor_get_current(probe_reading_t out[NUM_PROBES])
{
    xSemaphoreTake(s_current_mutex, portMAX_DELAY);
    memcpy(out, s_current, sizeof(s_current));
    xSemaphoreGive(s_current_mutex);
}

static volatile uint8_t s_fan_pct = FAN_NO_DATA;

void temp_sensor_set_fan_pct(float pct)
{
    s_fan_pct = (uint8_t)lroundf(pct < 0 ? 0 : pct > 100 ? 100 : pct);
}

static uint32_t uptime_s(void)
{
    return (uint32_t)(esp_timer_get_time() / 1000000);
}

// Caller holds s_history_mutex.
static void history_append_locked(const hist_entry_t *e)
{
    s_history[s_history_head] = *e;
    s_history_head = (s_history_head + 1) % HISTORY_LEN;
    if (s_history_count < HISTORY_LEN) {
        s_history_count++;
    }
}

void temp_sensor_push_history(void)
{
    probe_reading_t r[NUM_PROBES];
    temp_sensor_get_current(r);

    hist_entry_t e;
    time_t now = time(NULL);
    e.t = now > UNIX_TIME_VALID ? (uint32_t)now : uptime_s();
    for (int i = 0; i < NUM_PROBES; i++) {
        e.v[i] = isnan(r[i].temp_f) ? NO_DATA : (int16_t)lroundf(r[i].temp_f * 10);
    }
    e.fan = s_fan_pct;

    xSemaphoreTake(s_history_mutex, portMAX_DELAY);
    history_append_locked(&e);
    xSemaphoreGive(s_history_mutex);
}

void temp_sensor_reset_history(void)
{
    xSemaphoreTake(s_history_mutex, portMAX_DELAY);
    s_history_count = 0;
    s_history_head = 0;
    xSemaphoreGive(s_history_mutex);
    temp_sensor_push_history();
}
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

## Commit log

2026-08-24 Initial esp32_smoker project skeleton (ESP-IDF v5.5.3)
2026-08-24 Add smoker firmware: wifi provisioning, dual-probe temps, web dashboard, SD logging
    - Wi-Fi manager: connects with saved NVS credentials, falls back to a SoftAP
    with network scan/connect served over HTTP when no network is reachable
    - ADC-based meat/grill temperature probes via the IDF 5.x oneshot+cali API
    - esp_http_server dashboard (embedded index.html) with live readouts and a
    vanilla-JS canvas chart, backed by /api/status, /api/history, /api/scan,
    /api/wifi
    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
2026-09-26 Port smoker firmware to XIAO ESP32C3 with alerts, flash log and cook plans
    Port the Arduino smoker_thermometer.ino feature set to ESP-IDF and retarget
    the Seeed XIAO ESP32C3.
    Hardware / probes
    - Target esp32c3 (4 MB flash, USB Serial/JTAG console, custom partition
    table with a 1.5 MB app and a LittleFS "storage" partition).
    - Three probes (pit + 2 meat) on A0-A2 with 100k dividers; Maverick
    ET-72/73 Steinhart-Hart coefficients, verified in boiling water.
    - Per-probe open/short detection with a computed lowest-readable temp.
    Alerts (ntfy)
    - Pit low (arms after warm-up, configurable confirm delay), pit high, pit
    probe lost, meat almost done / done; ntfy server and topic set from the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
    [partitions.csv]
2026-09-27 Add PID fan control, fan graph and fan alert
    Fan hardware / control
    - 12 V PC fan on GPIO6 (D4) through a 2N2222, driven by slow 50 Hz PWM
    (13-bit LEDC), which lets the fan run steadily down to ~5%.
    - Auto mode: PID holds the pit target (Kp/Ki/Kd editable on the page,
    default Kp 4, Ki 0, Kd 0), 5% minimum when on, 1 s start-up kick,
    integral kept within 0-100%. Manual and Off modes.
    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
2026-09-27 Show fan P/I/D terms as whole numbers
    The PID terms were rounded to one decimal in single-precision float, which
    serialized as long decimals (e.g. 36.400001525878906) in /api/now. Round
    them to whole numbers in the firmware and again on the page.
2026-09-27 Retry home Wi-Fi in the background while on the fallback AP; add OTA TODO
    Once the fallback SoftAP started, the device never tried the home network
    again, so a router reboot mid-cook left it stranded in AP mode (alerts
    queued and eventually dropped). Now a background task makes one connection
    attempt every WIFI_RECONNECT_SEC (60 s) while the AP is up, alternating the
    secrets.h network and the one saved from the page. The AP stays up
    meanwhile; on success the AP is turned off as before.
    - Skip retries while a page-requested scan runs and for a round after the
    user presses Connect.
    - Show the real network name after connecting (it kept the AP's name).
    - TODO.txt: plan and notes for over-the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
    [config.h]
2026-10-05 Added Kicad work Added circuit diagram
2026-10-05 Added kicad
    [smoker.kicad_pcb, smoker.kicad_sch]
